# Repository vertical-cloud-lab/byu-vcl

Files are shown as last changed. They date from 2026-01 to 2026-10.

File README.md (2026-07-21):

# byu-vcl
Vertical Cloud Lab @ BYU

- [3D Printing SOP (Bambu Lab H2D, incl. multi-material PLA + TPU)](3d-printing-sop.md)
- [Thermo-Calc input for the 100 g ultrasonic atomization mixture](thermo-calc-100g-mixture-composition.md)

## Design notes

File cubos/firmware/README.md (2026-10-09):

# PANDA Arduino firmware — the VCL build

The Arduino Uno on `/dev/ttyACM0` runs **one** firmware that serves the
capper, the line-break sensor, the lights *and* the pipette plunger. Anything
flashed here affects the capper too, so nothing in this directory should be
applied casually.

Upstream: [`BU-KABlab/PANDA_Arduino`](https://github.com/BU-KABlab/PANDA_Arduino)
@ `228615b` ("fixed mixing function for pipette", 2025-08-27).

## 2026-10-07: the board runs `panda_vcl_p20gen2_tic796_fastmove_spread_20261007.hex`

Fix B for the TMC2209: the 10-01 image with spreadCycle instead of StealthChop, one line in
`setupMotor()` ([`panda-arduino-spreadcycle.patch`](panda-arduino-spreadcycle.patch)):

| call | was | now |
| --- | --- | --- |
| `setupMotor()` | `enableStealthChop()` | **`disableStealthChop()`** |

The library's `initialize()` turns `pwm_autoscale` off and nothing turns it back on. In
StealthChop that leaves `IRUN`/`IHOLD` scaling a fixed PWM amplitude instead of regulating the
current, about 0.1 A, and the plunger didn't move. In spreadCycle the chip regulates to them,
so the current table below is now what the coils get whenever the writes land. Built in
`~/panda_fw_vcl_tic796_fast_spread`, a copy of `~/panda_fw_vcl_tic796_fast`. The copy rebuilt
to the 10-01 image byte-for-byte before the edit. The new image is the same 17,468 bytes and
differs in one instruction: `andi r24, 0xFB` → `ori r24, 0x04`, setting GCONF bit 2
(`en_SpreadCycle`). `avrdude -U flash:v` matched the 10-01 image before the upload and this one
after it. The flash was read back first, as
[`../results/tmc2209_spreadcycle_20261007/flash_before_20261007.hex`](../results/tmc2209_spreadcycle_20261007/flash_before_20261007.hex).
On hardware: `tmc2209_probe.py` passed and `pipette_test` ran 12/12
([`../results/tmc2209_spreadcycle_20261007/`](../results/tmc2209_spreadcycle_20261007/README.md)).
The Tic ignores the UART writes, so this image also serves the Tic. To go back, flash
`panda_vcl_p20gen2_tic796_fastmove_20261001.hex` with the `avrdude` command at the end of this
file.

## 2026-10-01: the board ran `panda_vcl_p20gen2_tic796_fastmove_20261001.hex`

The 796 image with `MOVE_TO` sped up (speed change 3 in
[`../docs/pipette-setup-and-troubleshooting.md`](../docs/pipette-setup-and-troubleshooting.md#speed)).
Both changes since `panda-arduino-p20-and-driver-status.patch` are in
[`panda-arduino-tic796-and-fast-moveto.patch`](panda-arduino-tic796-and-fast-moveto.patch).

| constant / function | was | now |
| --- | --- | --- |
| `MOVEMENT_VELOCITY` | 2500.0 (~2,400 steps/s, ~3 mm/s) | **10000.0**: `stepMotor()`'s 100 µs floor, ~8,700 steps/s (~11 mm/s), the rate `ASPIRATE` already ran at because CubOS sends it speed 0 |
| `EJECT_VELOCITY` | — | **2500.0**, new |
| `movePipetteTo()` with no speed | everything at `MOVEMENT_VELOCITY` | any leg past `BLOWOUT_POSITION` (the tip-ejector push) at `EJECT_VELOCITY`; a move from below blowout goes fast to 32.5 first |

Built in `~/panda_fw_vcl_tic796_fast`, a copy of `~/panda_fw_vcl_tic796`:
17,468 bytes. `avrdude -U flash:v` matched the 09-30 image before the upload
and this one after it ([`../results/pipette_test_20261001/`](../results/pipette_test_20261001/SUMMARY.md)).
On hardware: `MOVE_TO 28.0` from 0 went from 9.29 s to 2.56 s, `MOVE_TO 46.5`
stayed at 4.65 s, and a post-run plunger `HOME` showed no lost steps. To go
back: flash `panda_vcl_p20gen2_tic796_20260930.hex` with the `avrdude` command at
the end of this file, or `pio run -e uno -t upload` in `~/panda_fw_vcl_tic796`.

## 2026-09-30: the board ran `panda_vcl_p20gen2_tic796_20260930.hex`

The pipette driver is now a Pololu Tic T500 in STEP/DIR mode, whose finest step
is 1/8 ([`../docs/tic-t500-pipette-setup.md`](../docs/tic-t500-pipette-setup.md)).
This image is `panda_vcl_p20gen2_20260917.hex` with two constants changed in
`include/Pipette.h`:

| constant | was | now |
| --- | --- | --- |
| `STEPS_PER_MM` | 1592.0 (TMC2209 at 1/16) | **796.0** (Tic at 1/8) |
| `MICROSTEPPING` | 16 | **8** (only feeds the TMC2209 setup call, which now writes to nothing) |

Built on the Pi from `~/panda_fw_vcl`, the tree that built the 09-17 image:
an unchanged rebuild reproduced that image byte-for-byte, and this one differs
from it in 5 bytes, all `ldi` immediates for those two constants. Flashed and
verified before and after with `avrdude -U flash:v`; record in
[`../results/pipette_test_20260930/`](../results/pipette_test_20260930/README.md).
796 is the safe choice while the scale is unconfirmed by a ruler: if 1592 were
right after all, every move would come out half as long rather than twice as
long. To go back: flash `panda_vcl_p20gen2_20260917.hex` with the `avrdude`
command at the end of this file.

The sections below describe the images before this one.

## ⚠️ 2026-09-17: a newer image is built and committed but **NOT flashed**

`panda_vcl_p20gen2_20260917.hex` corrects the plunger planes and the driver
current to Opentrons' own **P20 GEN2** figures (table below). It could not be
programmed: `avrdude` cannot sync with the board at any baud, because the
Arduino's serial link is corrupting data in both directions. Evidence and the
bench checks are in
[`../results/pipette_p20gen2_20260917/README.md`](../results/pipette_p20gen2_20260917/README.md).

**So the board still runs `panda_vcl_p20_20260915.hex`.** Once one `STATUS`
round-trip parses again, flash with:

```bash
cd ~/panda_fw_vcl && ~/.venvs/pio/bin/pio run -e uno -t upload --upload-port /dev/ttyACM0
```

`pio` is the way to do it — it drives the auto-reset correctly, where a bare
`avrdude` invocation on this Pi does not.

## What is on the board (2026-09-15)

| file | what it is |
| --- | --- |
| `flash_20260915T220346Z.hex` | **Backup of the flash as it was before this change.** Read with `avrdude -U flash:r:...:i` at 2026-09-15 22:03 UTC. Restores the board exactly. |
| `panda-arduino-p20-and-driver-status.patch` | The VCL delta against upstream `228615b`. **Regenerated 2026-09-17**: five files, +161/-12. Verified with `git apply --check` against a fresh clone at `228615b`, and the fresh clone builds. |
| `panda_vcl_p20_20260915.hex` | The image actually flashed on 2026-09-15, and **still what is on the board**. |
| `panda_vcl_p20gen2_20260917.hex` | The P20 GEN2 image. Built and verified, **not flashed** — see the warning above. 17 382 bytes, 53.9% flash, 1429 bytes RAM. |

The patch previously documented as "four files" also carries a
`platformio.ini` change (dropping `lib_extra_dirs = ~/Documents/Arduino/libraries`,
a path that does not exist on the Pi) that the earlier regeneration missed. It
is captured now.

**The backup proved the provenance.** Parsed and compared byte-for-byte, the
16 308 program bytes read off the board were **identical** to a local build of
upstream `228615b` — so the board really was running stock upstream, and the
VCL image is a provably minimal delta from it.

`panda_vcl_p20_20260915.hex` is the exact 17 370-byte image that was written and
verified by avrdude. A rebuild reproduced it bit-for-bit in one environment, but
**the build is not reproducible in general**: `platformio.ini` pins its library
dependencies with `^` ranges, so a clone that resolves a different minor version
builds a slightly different image (17 364 bytes in one such case). Flash the
committed hex if you want exactly what was on the board; rebuild from the patch
if you want the source of truth.

## Upstream `main` does not compile

`228615b` gives a default argument for `dwell_ms` in **both** the declaration
in `include/Pipette.h` and the definition in `src/Pipette.cpp`, which is a hard
C++ error:

```
src/Pipette.cpp:355:86: error: default argument given for parameter 4 of
  'bool mixInPlace(int, float, float, float)'
```

The patch drops the duplicate from the definition; the header keeps it, so the
default is unchanged. Worth sending upstream — as it stands nobody can build
`main`.

## What changed, and why

### Pipette constants — P20 GEN2, from Opentrons

The pipette on the head is a **P20 GEN2** — legible on the body in
`../results/pi5_des4_provision_20260914/pipette_label_p20_gen2.jpg` and in
campaign 36's `cam0_csi0` frame, and confirmed by Ben on 2026-09-17. Ursa's
records had said P300 GEN2, and the 2026-09-15 image was a hybrid: P300
plunger planes with P20 volume limits. Resolved in favour of the P20 GEN2.

Authority is Opentrons
`shared-data/pipette/definitions/1/pipetteModelSpecs.json`, keys
`p20_single_v2.0`/`2.1`/`2.2` (identical positions in all three). Opentrons
states plunger planes as signed offsets in a frame whose `top` is the home
reference; this firmware measures distance **downward** from home, so each
value is `top - <field>` with `top = 19.5`.

| constant | stock | 2026-09-15 | **2026-09-17** | why |
| --- | --- | --- | --- | --- |
| `MAX_VOLUME` | 300.0 | 20.0 | **20.0** | P20 GEN2. `STATUS` reported `max_vol: 300.00` for months. |
| `MIN_VOLUME` | 5.0 | 1.0 | **1.0** | P20 GEN2. The P300 clamp is why `ASPIRATE 0.5` always landed at 35.45: 0.5 clamped up to 5. |
| `PRIME_POSITION` | 36.0 | 36.0 | **28.0** | Opentrons `bottom` −8.5. 36.0 is the P300's plane. |
| `BLOWOUT_POSITION` | 44.0 | 44.0 | **32.5** | Opentrons `blowout` −13. |
| `DROP_TIP_POSITION` | 55.0 | 55.0 | **46.5** | Opentrons `dropTip` −27. Also the ceiling `moveTo` clamps at. |
| `UL_TO_MM` | 0.1098 | 1.8 | **1.34** | `1 / 0.746`, and 0.746 µL/mm is the asymptote of Opentrons' own `ulPerMm` table for `p20_single_v2.1`. The 1.8 was only `36.0 / 20`, i.e. read off a P300 plane. |
| `RUN_CURRENT_PERCENT` | 50 | 17 | **20** | → CS 6, **1.02 A peak** = Opentrons `plungerCurrent` 1.0 A. See the current note below. |
| `HOLD_CURRENT_PERCENT` | 30 | 10 | **5** | → CS 1, **0.29 A peak** = Opentrons `idleCurrent` 0.3 A. |

Two cross-checks that `UL_TO_MM 1.34` is derived rather than guessed:

- The same method applied to the P300 gives 9.1 µL/mm, reproducing
  `UL_TO_MM 0.1098` — the one constant in this firmware that was
  independently calibrated. So the method is validated against a known-good
  value.
- A full-scale 20 µL aspirate travels `20 × 1.34 = 26.8 mm` up from
  `PRIME_POSITION 28.0`, landing the plunger at **1.2 mm**: inside the 28 mm
  top-to-bottom stroke with a small dead band, which is how Opentrons has it.

**All three planes moved down, so every commanded plunger travel is shorter
than before** — the safe direction — and `0 < prime < blowout < drop_tip`,
which `aspirate`/`dispense`/`moveTo` rely on, still holds.

⚠️ **Nominal, not calibrated.** These are Opentrons' figures for the model,
not a measurement of this unit. `UL_TO_MM` needs a gravimetric check once
liquid actually moves.

These three planes now match CubOS's `p20_single_gen2` entry exactly; see
[`../patches/README.md`](../patches/README.md).

### Driver current — the sense resistor is 0.05 Ω, not 0.11 Ω

The 2026-09-15 value of 17 was scaled from an assumed 0.11 Ω sense resistor
and a 500 mA target taken from science-jubilee's Duet config. Both were wrong.
Ursa read `R1`/`R2` = **0.05 Ω** off the Adafruit 6121 schematic, and
Opentrons' own `p20_single_v2.x` runs the plunger at **1.0 A**, idling at
0.3 A. With `vsense = 0` (`enableVSense()` is never called) and the library's
`CS = map(percent, 0, 100, 0, 31)`:

```
I_rms = ((CS+1)/32) * (0.325 / (0.05 + 0.02)) / sqrt(2) = ((CS+1)/32) * 3.283 A
```

| percent | CS | I_rms | I_peak | |
| --- | --- | --- | --- | --- |
| 50 | 15 | 1.64 A | 2.32 A | stock — over the **breakout's** 2 A rating, not just the motor's |
| 17 | 5 | 0.62 A | 0.87 A | 2026-09-15 |
| **20** | **6** | **0.72 A** | **1.02 A** | Opentrons `plungerCurrent` |
| **5** | **1** | **0.21 A** | **0.29 A** | Opentrons `idleCurrent` |

Hold current is mapped to IHOLD **independently** of run current by this
library, not as a percentage *of* it — so the two rows have to be chosen
together. ⚠️ **Fit the Adafruit 1515 heat sink before running at this
current.**

⚠️ **Whether this table is in force depends on power-up order, and cannot be
read back yet.** `RUN_CURRENT_PERCENT` reaches the chip through
`setRunCurrent()`, a UART *write*. `UART` runs straight from A1 to `PDN_UART`,
writes need no reply, and SoftwareSerial's 9600 baud clears the datasheet's
9000 minimum — so whenever the Arduino boots with the 12 V already up (including
every time a host opens the port, which resets it), `setOperationModeToSerial()`
very probably lands, takes the VREF trimmer out of circuit, and this table
governs. If the Arduino boots before the 12 V, the writes reach an unpowered chip
and the trimmer governs until the next reset. So **keep the two matched**: VREF
at 0.55–0.59 V on the wiper gives 1.02–1.09 A peak, the same as the 20 row; it
has been at 0.586 V since 2026-09-26. Full clockwise on the Adafruit 6121 is
~1.5 A rms / 2.2 A peak — its 10 kΩ trimmer is fed from `5VOUT` through 33 kΩ —
not the ~3.3 A rms stated here until 2026-09-26. `IFCNT` will settle the
question once the bridge resistor is on the TX side. See §22.4–22.5 of
[`../docs/opentrons-pipette-wiring.md`](../docs/opentrons-pipette-wiring.md).

### The TMC2209 library is now vendored and patched

`lib/TMC2209/` in the firmware project holds a patched copy of the janelia
library: reads over `SoftwareSerial` cannot work unpatched, which is why
`CMD_PIPETTE_DRIVER_STATUS` always answered `comm = 0`. The patch is
[`../patches/tmc2209-softwareserial-read.patch`](../patches/tmc2209-softwareserial-read.patch);
it is **not** sufficient on its own — the bridge resistor also has to move to
the TX side. Vendoring into `lib/` rather than `.pio/libdeps/` is deliberate
and was verified, not assumed: a sentinel `#error` in the `lib/` copy fails
the build, so that copy is provably what compiles.

`PRIME_POSITION` 36.0, `BLOWOUT_POSITION` 44.0 and `DROP_TIP_POSITION` 55.0 are
**unchanged** — they are mechanical plunger positions, and `UL_TO_MM` 1.8 is
derived from `PRIME_POSITION`, so moving one means re-deriving the other.
They may still be P300 figures; a P20's usable travel is shorter, and
`DROP_TIP_POSITION` 55.0 in particular is worth checking against the real
plunger before anything relies on the ejector.

### New: `CMD_PIPETTE_DRIVER_STATUS = 29`

Ben bridged `RX_PIN` (A0) to `TX_PIN` (A1) with 10 kΩ on 2026-09-15, which is
what makes a TMC2209 read possible — PDN_UART is half duplex, so the driver
answers on the wire it was addressed on, and without the bridge the Arduino
could only ever talk.

Before this, `setupMotor()` wrote six registers and checked none of them, and
no command exposed driver state. A driver sitting at minimum current with its
output stage off was indistinguishable, at the serial port, from a healthy one.

```
OK:{"msg":"Driver status","v":[<comm>,<flags>,<current_scaling>]}
```

* `comm` — `0` no reply at all · `1` communicating but not set up (driver power
  was lost after `setup()`, so defaults reloaded) · `2` set up and communicating
* `flags` — bitmask, `DRVSTATUS_*` in `include/Pipette.h`: over-temperature
  warning/shutdown, short-to-ground A/B, low-side short A/B, **open-load A/B**,
  the 120/143/150/157 °C flags, stealthChop, standstill, hardware-disabled
* `current_scaling` — the driver's actual CS value, 0-31, or `-1` if unread

`open_load_a`/`open_load_b` answer the coil-continuity question without a
meter. Read it with CubOS's own link:

```python
from cubos.instruments.controllers.pawduino import PawduinoLink
link = PawduinoLink.acquire("/dev/ttyACM0", 115200); link.connect()
print(link.send_command(29, timeout=15))
```

## Rebuild / reflash / restore

PlatformIO lives in a user venv on the Pi (`~/.venvs/pio`), toolchain under
`~/.platformio` — no sudo, nothing system-wide.

```bash
git clone https://github.com/BU-KABlab/PANDA_Arduino.git ~/panda_fw_vcl
cd ~/panda_fw_vcl && git checkout 228615b
git apply ~/byu-vcl/cubos/firmware/panda-arduino-p20-and-driver-status.patch
~/.venvs/pio/bin/pio run -e uno -t upload --upload-port /dev/ttyACM0
```

To put the board back exactly as it was:

```bash
AVRDUDE=~/.platformio/packages/tool-avrdude/avrdude
CONF=$(find ~/.platformio -name avrdude.conf | head -1)
"$AVRDUDE" -C "$CONF" -c arduino -p atmega328p -P /dev/ttyACM0 -b 115200 -D \
    -U flash:w:~/byu-vcl/cubos/firmware/flash_20260915T220346Z.hex:i
```

Close every serial handle first — CubOS holds `/dev/ttyACM0` for the whole of a
run, and opening the port resets the board.

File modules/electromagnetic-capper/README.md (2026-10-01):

# Electromagnetic Vial Capper/Decapper Module

Magnet-based (rotation-free) vial capping/decapping module for automated liquid handling,
replicated from the **PANDA-film** self-driving lab developed by Keith A. Brown's group
(KABlab) at Boston University.

- **Paper:** Quinn, H.; Robben, G. A.; Zheng, Z.; Yan, J.; Li, Y.; Yang, Z.; Politi, M.;
  Peek, N.; Pozzo, L.; Werner, J. G.; Brown, K. A. *PANDA-film: an automated system for
  electrodeposition of polymer thin films and their wetting analysis.*
  [arXiv:2601.07043](https://arxiv.org/abs/2601.07043) (2026). CC BY 4.0.
  A copy is committed in [`paper/`](paper/) together with its license.
- **Source hardware/software repo:** [BU-KABlab/PANDA-BEAR](https://github.com/BU-KABlab/PANDA-BEAR) (GPL-2.0)
- **Arduino firmware:** [BU-KABlab/PANDA_Arduino](https://github.com/BU-KABlab/PANDA_Arduino)
- **Community discussion:** [Electromagnetic capper thread on accelerated-discovery.org](https://accelerated-discovery.org/t/electromagnetic-capper/579)
- **Tracking issue:** vertical-cloud-lab/byu-vcl#147

## How it works

Commercial capper/decappers grip and rotate caps. This design avoids rotary motion
entirely: a small **5 V, 50 N electromagnet** mounted on the gantry head picks up
custom **press-fit caps that carry a steel disc**, and an **IR break-beam sensor**
confirms successful cap pickup and replacement (paper Figure 2A–B).

Custom caps are fabricated by:

1. 3D printing the cap body in **PLA** (the authors used a Bambu A1; any well-tuned FDM
   printer works) — [`cad/VialCap16mm.step`](cad/VialCap16mm.step)
2. Filling the cap interior with **PDMS (Sylgard 184, 10:1 by weight base:curing
   agent)** for chemical resistance and sealing. The paper calls the second component
   the "crosslinker"; on the Sylgard 184 kit itself it is labeled **Silicone Elastomer
   Curing Agent** — same thing.
3. Affixing a **steel disc with 3M adhesive** into the recessed region on top of the cap

The electromagnet sits in a 3D-printed holder
([`cad/PAW-V2-ElectromagnetMount.step`](cad/PAW-V2-ElectromagnetMount.step)) alongside
the IR break-beam sensor. It is switched by an Arduino Uno through an IRLZ44 logic-level
MOSFET with a 1N5819 flyback diode across the coil.

**Validated performance (paper §3.1, Figure 2C):** 100% capping/decapping success with
tolerance to **~3 mm of vertical approach-height misalignment**, tested across five
independently fabricated caps × 10 decap/recap cycles per height step (0.2 mm steps).

## Contents

| Path | Description |
|---|---|
| [`BOM.md`](BOM.md) | Bill of materials for the ME order (procure + print + fabricate) |
| [`paper/panda-film-2601.07043.pdf`](paper/panda-film-2601.07043.pdf) | The paper (arXiv:2601.07043, CC BY 4.0) |
| [`paper/LICENSE-CC-BY-4.0.txt`](paper/LICENSE-CC-BY-4.0.txt) | Paper license |
| [`cad/VialCap16mm.step`](cad/VialCap16mm.step) | Custom vial cap (print one per stock vial) |
| [`cad/PAW-V2-ElectromagnetMount.step`](cad/PAW-V2-ElectromagnetMount.step) | Electromagnet + sensor mount for the gantry head |
| [`cad/9VialHolder20mL_TightFit.step`](cad/9VialHolder20mL_TightFit.step) | 9-position 20 mL vial rack for the deck |
| [`cad/LICENSE-GPL-2.0.txt`](cad/LICENSE-GPL-2.0.txt), [`cad/NOTICE.txt`](cad/NOTICE.txt) | License/notice for the CAD files (from PANDA-BEAR) |

Note on sources: the paper was submitted to arXiv as PDF only — no LaTeX source is
available from the e-print endpoint (it returns the identical PDF), so only the PDF is
committed here.

## Build references

- [PANDA-BEAR Construction Guide](https://github.com/BU-KABlab/PANDA-BEAR/blob/main/documentation/Construction.md) — PAW assembly, parts checklist
- [PANDA-BEAR Arduino Wiring](https://github.com/BU-KABlab/PANDA-BEAR/blob/main/documentation/Arduino-Wiring.md) — circuit diagrams (electromagnet MOSFET driver, IR sensor)
- [PANDA-BEAR full BOM](https://github.com/BU-KABlab/PANDA-BEAR/blob/main/documentation/documents/bom.md) — complete PANDA-film parts list (superset of this module)
- [3D print files (all)](https://github.com/BU-KABlab/PANDA-BEAR/tree/main/documentation/3D-prints)

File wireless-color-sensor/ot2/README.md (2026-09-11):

# OT-2 colour X-scan: pick up from slot 10, read three X positions over the scan slot

The test @timothy-commins asked for in
[issue #33](https://github.com/vertical-cloud-lab/byu-vcl/issues/33):

> make the color sensor pick up the enclosure from well 10, and then place it
> into 3 different places in the x direction on well 8. the test will then
> test the color at each of the 3 places in well 8

```
seated baseline read
  -> pick up the enclosure from slot 10        (proven descent/entry/press recipe)
  -> grip check                                (the sensor's own counts confirm the lift)
  -> carry to slot 8, x = centre - 30 mm       descend to the read height, read 3x
  -> carry to slot 8, x = centre               descend to the read height, read 3x
  -> carry to slot 8, x = centre + 30 mm       descend to the read height, read 3x
  -> carry back to slot 10, reseat, home
  -> reseat-confirm read
```

Every reading goes to `digital-wetlab.sensor-data` in MongoDB and to a local
JSON file.

## Run it

The script has to run on **the machine with the USB-Ethernet cable to the
OT-2**. The robot answers only on the link-local address
`169.254.51.252:31950`, and the same machine needs internet for HiveMQ and
MongoDB — so it must be one host, not two.

As of 2026-09-09 that machine is the Pi behind **`RPI_STREAM_CAM_HOSTNAME`**,
not the one behind `OT2_STREAM_CAM_HOSTNAME`. The adapter is a Realtek RTL8153
on `eth1` holding `169.254.210.205/16`. The `OT2_STREAM_CAM_HOSTNAME` Pi has no
ethernet interface and no USB devices at all, so `169.254.51.252` times out from
there — which is what "the OT-2 is not answering" looked like in the previous
session. Check with `ip -4 -br addr` before concluding the robot is down.

The venv is already set up on that Pi at `~/.venvs/xscan` (`paho-mqtt`,
`pymongo`, `requests`; the system Python 3.13 is externally managed, hence the
venv). To rebuild it elsewhere:

```bash
python3 -m venv ~/.venvs/xscan
~/.venvs/xscan/bin/pip install paho-mqtt pymongo requests

export MQTT_BROKER=... MQTT_PORT=8883 MQTT_USERNAME=... MQTT_PASSWORD=...
export PICO_ID=... MONGODB_URI=... MONGODB_DATABASE=digital-wetlab
```

Then, in order:

```bash
# 0. is the enclosure actually on the deck? One HTTP call, no motion.
~/.venvs/xscan/bin/python deck_photo.py -o deck.jpg

# 1. confirm the pickup coordinate. Homes, hovers the BARE nozzle 30 mm above
#    the computed pickup point, and stops. Slide the base under it.
~/.venvs/xscan/bin/python run_xscan_test.py --align

# 2. sensor + database only -- the robot never moves
~/.venvs/xscan/bin/python run_xscan_test.py --dry-run

# 3. the real test
~/.venvs/xscan/bin/python run_xscan_test.py
```

**Step 0 is not optional when nobody is standing at the robot.** The grip check
catches an empty pickup, but only after the nozzle has already descended and
pressed at slot 10. A photograph costs one HTTP call and answers the same
question before anything moves — on 2026-09-09 it found the deck completely
bare, with nothing in slot 10 or slot 8.

Run `--align` **every time the base is moved**. The slot-10 pickup coordinate
below is the proven slot-8 coordinate translated by the OT-2 slot pitch, not a
measured one — `--align` turns that assumption into a 30-second visual check
before anything presses down on the enclosure.

## Deck layout

| | |
|---|---|
| Enclosure base | slot **10**, socket at (36.55, 315.5) |
| Read positions | slot **8**, x = 166.38 / 196.38 / 226.38, all at y = 225.0, z = 120.0 |
| Pipette | `p300_single_gen2`, left mount |

The pickup offset within the slot is (36.55, 44.0) — the same offset the
[PR #60 sessions](../camera/) used for the base in slot 8, so slot 10 gives
(0, 271.5) + (36.55, 44.0). The read Y uses the same within-slot 44.0 mm, which
lands on y = 225.0 in slot 8 — the exact Y those camera-verified sessions ran at.

**Only X changes between the three reads.** The 2026-08-10 session measured
that raw counts are dominated by pose — the same sensor read ~15× higher lifted
than seated — so a scan that also varied Y or Z would be measuring the pose
rather than the sample. Y, Z, settle time and command values are identical at
all three positions.

At z = 120 the nozzle is 29.5 mm above its press depth, so the enclosure's
aperture sits about **29.5 mm above the deck**. If you put a plate or a
backlight in slot 8, raise or lower with `--read-z`; the aperture height is
always `read_z - 90.5`.

## Motion recipe

Unchanged from the recipe that completed **9 of 9** pick-and-reseat cycles in
July/August 2026 ([`../camera/pickup-test-2026-08-10-pick-and-reseat/`](../camera/pickup-test-2026-08-10-pick-and-reseat/)).
Only the start slot and the read positions are new.

| stage | value |
|---|---|
| Descent ladder | z 170 → 150 → 120 → 105 → 101 → 99 |
| Straight entry | z = 95 @ 5 mm/s |
| Press | z = 90.5 @ 5 mm/s (≥ 7 mm engagement, so eject works later) |
| Lift test | z = 110 + 4 s dwell |
| High lift | z 130 → 150 → 170 @ 15 mm/s |
| Carry | 8.5 mm segments @ 10 mm/s |
| Read | descend to z = 120 @ 10 mm/s, settle 1.5 s, read ×3 |
| Drop-off | pickup x − 6 mm (anti-tilt), staged descent 130 → 110 → 108 → 101 → 95.5 |
| Eject | `dropTipInPlace`, clear to z = 128, home |

The staged climbs and segmented carries are not decoration: on 2026-07-31 the
module came off the nozzle during a single long Z move.

## Safety behaviour

**Grip check.** After the lift test the script takes two readings and compares
them with the seated baseline. Lifting the enclosure off its base uncovers the
aperture, which raised the counts ~15× in the 2026-08-10 session. If the counts
do not rise by at least 2× (`--grip-ratio`), the nozzle came up empty and the
script aborts before the carry rather than flying an empty nozzle to slot 8 and
then "reseating" it next to a still-seated enclosure. `--skip-grip-check`
disables it.

**Reseat on failure.** Any exception during the carry or the reads triggers the
reseat leg and a home before the script exits, so the enclosure is not left
hanging. If that also fails, the message points at
[`../cad/recover_reseat.py`](../cad/recover_reseat.py), which recovers a
stranded grip — but look inside the robot first.

**Preflight.** Before the robot is touched: the broker connection is proved by
publishing a probe to our own topic and waiting for the echo (a broker can grant
a subscription and then deliver nothing), the sensor is proved by taking the
seated baseline, and every coordinate is bounds-checked against its slot.

## Files

| file | what it is |
|---|---|
| `run_xscan_test.py` | the test |
| `sensor_read.py` | one MQTT connection held open for the run; `read()` returns the 8 channels |
| `deck.py` | OT-2 slot origins and slot/offset maths, with no `opentrons` dependency |
| `check_reachability.py` | pushes every planned coordinate through the Opentrons simulator |
| `stream_index.py` | every reading → its UTC instant → a timestamped livestream link |
| `frames_from_stream.py` | pulls one frame per measurement and OCR-verifies it against the clock burned into the stream |
| `plot_spectra.py` | 300 px spectra in the light-mixing `basic_plotting.py` style |
| `build_gallery.py` | stitches frame + spectrum + link into `measurement-gallery.md` |
| `stream_grab_pi.py` | the Pi-side half of the frame grab (lives there as `~/ytframes/grab.py`) |
| `led_probe.py` | zero-motion check of whether the module's LEDs respond (they do not) |
| `deck_photo.py` | one HTTP call to the OT-2's own overhead camera |

## Lining a reading up against the livestream

`python3 stream_index.py` writes `measurement-stream-index.{json,md}`: all 114
readings of the 2026-09-09 session with a UTC instant and a `?t=` link into the
archived stream. `frames_from_stream.py` then pulls the frame at each instant.

Two things to know before trusting a link:

* **The archive timeline is not wall clock.** For `bQDrYpT3vaE` it runs 67 s
  behind `release_timestamp` from the third hour onward — a step, not a drift.
  That is more than one scan position, so `--offset-shift` is not cosmetic.
* **The stream burns a `%Y-%m-%d_%H-%M-%S` clock (lab local, UTC−6) into every
  frame**, which is how the offset is verified rather than assumed. Every
  committed frame records its OCR'd clock in `frames/frames.json`.

YouTube refuses player extraction from a GitHub Actions runner; the fetching
half runs over SSH on the stream-cam Pi (`~/ytframes/grab.py` there).

## Options

```
--home-slot 10 --scan-slot 8      which slots to use
--base-dx / --base-dy             where the socket sits within the home slot
--scan-dx -30,0,30                X offsets from the scan slot's centre (any number of them)
--scan-dy 44.0                    within-slot Y for the reads
--read-z 120 --carry-z 170        heights
--press-z 90.5                    pickup press depth; lower = deeper = tighter fit
--reads 3                         readings per position
--rgb 0,0,0                       R,Y,B sent with each read command
--align / --dry-run / --simulate  the three rehearsal modes
--no-mongo --out results.json     where the data goes
```

`--simulate` prints the whole motion plan with no robot and no sensor — useful
for checking a changed layout before taking it anywhere near hardware.

## What has been verified, and what has not

Verified on 2026-09-04 from CI:

- `sensor_read.py` against the live board — 8 channels back in 1.5 s.
- `--dry-run` end to end — baseline reads, MongoDB write into
  `digital-wetlab.sensor-data`, JSON output.
- `check_reachability.py` — all 28 planned coordinates in bounds for a
  left-mount P300; `deck.py`'s slot origins match the packaged Opentrons deck
  definition. Negative controls confirm the checker has teeth: `--scan-dx
  -100,0,100` is rejected as off-slot and `--read-z 250` is rejected as above
  the 218 mm Z limit.
- `--simulate` — 72 moves planned, segmentation and staging as intended.

Not verified on 2026-09-04: **the motion itself.** The OT-2 did not answer on
`169.254.51.252`, which was read at the time as a disconnected USB-Ethernet
adapter.

### 2026-09-09 — the robot answers; the deck is empty

That reading was half right. The adapter was never missing, it is on the *other*
Pi (see [Run it](#run-it)). From `RPI_STREAM_CAM_HOSTNAME` the robot answers
immediately:

```
GET /health -> 200  {"name": "OT2CEP20210722R13", "robot_model": "OT-2 Standard",
                     "api_version": "8.8.1", "system_version": "v1.19.6"}
GET /instruments    -> p300_single_gen2, left mount, ok=true
GET /calibration/status -> deckCalibration OK (2026-01-27)
```

Also verified this session, from the Pi that would drive the run:

- Sensor over MQTT — 8 channels, total 770 ± 1 across five reads, ~1.4 s each.
- `--dry-run` — broker delivery PASS, baseline reads, 2 documents written to
  `digital-wetlab.sensor-data`, JSON out.
- `--simulate` — 72 moves.
- `check_reachability.py` — 28/28 coordinates in bounds, slot origins match the
  packaged deck definition.
- **The maintenance-run command path, on the real robot.** Create run →
  `loadPipette` → `home` → `savePosition` → delete, all succeeded: pipette
  loaded in 2.4 s, home in 12.5 s, nozzle parked at (384.05, 349.93, 199.60).
  This is the path every move in the test goes through, and it had never been
  exercised before. Home was safe to run precisely because the deck was
  photographed empty first.

**The motion still did not run, for a different reason: the deck is bare.**
`deck_photo.py` shows all eleven slots empty — no enclosure, no base in slot 10,
nothing in slot 8. Running the test in that state would have descended on an
empty slot, come up with nothing, and aborted at the grip check without
measuring anything.

So the remaining blocker is now purely physical: stand the enclosure on its base
in slot 10, then run step 0, `--align`, and the test.

### 2026-09-09 — slot 7 at two heights; the LEDs were off the whole time

Two more complete cycles, both with slot 7 empty: the run asked for on #197
(`--scan-slot 7 --read-z 125`) and a control at the previous height
(`--scan-slot 7 --read-z 120`). The control exists because the requested run
changes both the slot and the height at once, so alone it cannot attribute the
difference to either. Grip check 5.1× and 5.3×; reseat confirmed on both.

Full write-up and data: [`results-slot7-2026-09-09.md`](results-slot7-2026-09-09.md).

Two things came out of it that change how the test should be run:

- **`--rgb` defaults to `0,0,0`, so every scan measures ambient light only.**
  The module's own illumination is never switched on. *Superseded in part later
  the same day:* `--rgb` turns out to be **inert** — the board acknowledges every
  level and colour but nothing lights (`led-probe-2026-09-09.json`), so "set
  `--rgb`" is not an available fix. Controlled illumination needs a working light
  source in the enclosure. This still reframes the "46% swing" finding: it is a
  symptom of reading with no illumination, not an inherent property of the deck.
- **Raising the aperture makes everything worse.** 5 mm higher cost 9–42% of the
  signal and made read-to-read repeatability 30–300× worse (0.03–0.07% at
  z 120 against 1–11% at z 125), and reversed the sign of the positional
  gradient. Slot 7 at z 120 gives ~7000 counts, a −5.5% gradient over 60 mm and
  reads that agree to within 2–5 counts; it beats both slot 8 and the raised
  pose on every measure. Default to it.

### 2026-09-09 — read z 129 with a 0.5 mm deeper press

Requested on #197 after the module worked loose and came off its base at the end
of the previous session: read 1 mm higher, press 0.5 mm deeper for a tighter fit.
`--press-z` was added for it, and it shifts the release height by the same delta
so the module is set down from the height the proven recipe used rather than
dropped from 0.5 mm up.

    run_xscan_test.py --scan-slot 7 --read-z 129 --press-z 90.0

Cycle completed, grip 4.6×, reseat confirmed at 436 against a seated 445. Full
write-up: [`results-z129-press90-2026-09-09.md`](results-z129-press90-2026-09-09.md).

Three things worth carrying forward:

- **A deeper press also raises the read height.** Seating the nozzle further into
  the socket makes the module ride higher on it, so `--read-z 129 --press-z 90.0`
  puts the aperture 39.0 mm off the deck — 1.5 mm above the previous run, not the
  1.0 mm the `--read-z` number alone suggests. `aperture_height_mm` in the run
  JSON is the number to compare across runs, not `--read-z`.
- **One clean cycle does not validate a grip fix.** The previous session's
  three-position cycle also completed cleanly; the module was lost during the
  longer second cycle that followed. And the grip *ratio* is a light reading at
  the lift height, not a measure of fit — a deeper press moves the aperture, so
  the ratio shifts for reasons unrelated to how tightly the module is held.
- **Bare deck is not spectrally flat, and differs by position.** At x = 93.88 the
  620 nm share is 28.6% against 20.9% at the slot centre, in the empty run and
  both paint runs alike. A per-position empty reference is the only valid
  baseline; "looks reddish" is not evidence of a red sample.

## 2026-09-09, late — why only yellow ever registers (no motion)

Re-analysis of every scan on record, prompted by the question on #197: if the
aperture clears the deck and passes over a vial at each stop, why does only one
colour show? Full write-up:
[`results-why-only-yellow-2026-09-09.md`](results-why-only-yellow-2026-09-09.md);
regenerate the figure with `python3 plot_why_only_yellow.py`.

- **Read height decides whether this instrument works.** Spread of the spectral
  shape across the three stops of an **empty** slot 7, worst channel, in points of
  share: **0.14 at z 120 · 1.52 at z 125 · 7.69 at z 128.** Fifty-five times worse
  for an 8 mm rise, with nothing on the deck. The colour effects reported earlier
  in the day are ~1.3 points, i.e. smaller than the artefact at the height they
  were measured at.
- **The height needed to clear a tall vial is the height at which measuring
  stops working.** Prefer flat opaque targets at z 120 over vials at z 128.
- **Occlusion and yellow paint have the same spectrum.** The room light carries 4×
  more flux in 583–670 than in 410–470, and 440/470 sit on a white LED's blue pump
  peak while 410 sits below it. So losing sight of the cool component reads as
  "440/470 down, 410 flat, red up" — indistinguishable from a yellow absorber
  without an illuminant of your own. Blue samples have no flux to reflect; red
  samples darken an already-red background, which is the artefact's own signature.
- **Check a claimed detection in absolute counts.** The "yellow" at x = 33.88 came
  with the total up 17% and 410 nm up 12% while 440 nm fell 25%. An absorber does
  not raise the total, and yellow's absorption edge is monotone below ~480 nm, so
  it must cut 410 at least as hard as 440. That was the room light changing between
  two runs six minutes apart, not a sample.
- **To settle it: move the sample, re-scan.** If the feature follows the vial it is
  real; if it stays at the same X it is the machine.

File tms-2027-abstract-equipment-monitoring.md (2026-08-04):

# TMS 2027 Abstract — Livestreaming Cameras for Equipment Monitoring

- **Meeting:** TMS 2027 Annual Meeting & Exhibition, Orlando, FL, March 14–18, 2027
- **Presentation type:** Poster
- **Target symposium:** *AI-Enabled Materials Processing: Integrating Accelerated Experimental Workflows and Processing-Aware Machine Learning* (Data-Driven and Computational Materials Design track; [flyer 021](https://www.tms.org/tms2027/downloads/flyers/TMS2027-CFA-Flyer-021.pdf))
  - The flyer explicitly welcomes "real-time process monitoring," "high throughput and data-aware experimental design," and "closed-loop experimental workflows that integrate synthesis, processing, characterization, testing, and iterative model-guided refinement" — the enabling-technology angle for accelerated/self-driving experimental workflows.
  - Alternate: *AI/ML/Data Informatics for Materials Discovery: Bridging Experiment, Theory, and Modeling* ([flyer 022](https://www.tms.org/tms2027/downloads/flyers/TMS2027-CFA-Flyer-022.pdf)) — lists "FAIR data principles, metadata frameworks, provenance, and interoperable infrastructure" as a topic of interest.
- **Abstract deadline:** July 1, 2026 (per flyer key dates)
- **Presenter:** Seth Leavitt

## Title

**Low-Cost Open-Source Camera Modules for Continuous Monitoring of Self-Driving Laboratories**

## Authors and Affiliations

| # | Author | Affiliation(s) | Role |
|---|---|---|---|
| 1 | Seth Leavitt | BYU Mechanical Engineering | Presenter |
| 2 | Yanghuang Liu | Acceleration Consortium, University of Toronto | Co-author |
| 3 | Jonathan Woo | Acceleration Consortium, University of Toronto | Co-author |
| 4 | Sterling G. Baird | BYU Mechanical Engineering; Acceleration Consortium, University of Toronto | PI |

## Abstract

*(Word limit: 150; current version: 147 words)*

As laboratories move toward higher autonomy, continuous equipment monitoring becomes
essential for debugging, provenance, and safety — echoing recent calls for aviation-style
"black box" recording in self-driving laboratories (SDLs). We present a fully open, low-cost
(<$100/module), many-camera, multi-site livestreaming infrastructure for SDL operations.
Unlike task-specific computer vision for real-time process control, each equipment module
receives a dedicated passive camera with tunable frame rate and resolution and failsafe
auto-restart for unattended operation. Dozens of modules deployed across multiple
institutions have achieved >99% uptime while collecting tens of thousands of hours of video.
Streams linked to timestamps and experiment metadata provide a visual audit trail
complementing structured records; the footage also yields heuristic utilization estimates
and, prospectively, robot-learning training data. Cameras capture only operators' hands and
forearms, a privacy-by-design choice for shared facilities housing furnaces, synthesis
platforms, and characterization instruments. All hardware, firmware, and documentation are
openly available (https://ac-training-lab.readthedocs.io/en/latest/devices/picam.html).

<!-- Source references: byu-vcl issue #9; AC Training Lab picam docs; AccelerationConsortium/streamingLambda -->
<!-- Framing informed by Edison Scientific feedback (PR #146): infrastructure novelty, visual audit trail,
     heuristic utilization, robot-learning as future work, black-box/provenance discourse (Leong et al. 2025),
     democratized SDL literature (Lo et al. 2024; Pelkie et al. 2025), materials-specific examples for TMS. -->

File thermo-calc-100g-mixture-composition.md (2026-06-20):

# Thermo-Calc input for the 100 g ultrasonic atomization mixture

This note converts the recorded **100 g mixture** in [issue #16 comment 4012488827](https://github.com/vertical-cloud-lab/byu-vcl/issues/16#issuecomment-4012488827) into a Thermo-Calc-friendly elemental composition in **wt.%**.

## Source masses

| Component | Measured mass (g) |
| --- | ---: |
| 1100 Al wire | 38.1640 |
| Si powder | 20.3042 |
| AlSi10Mg powder | 41.5472 |
| Total | 100.0154 |

## Composition assumptions

1. **1100 Al wire**  
   Treat as Al for the recommended Thermo-Calc input. AA1100 is **99.0 wt.% Al minimum**, but the supplied repo docs do not resolve the remaining trace-element breakdown tightly enough to support a better explicit element-by-element entry.

2. **Si powder**  
   The SDS in this repo (`silicon-powder-mcmaster-carr-sds-2014400 SDS SI101 011020.pdf`) lists **Si = 98.0-99.5 wt.%**. For a single nominal Thermo-Calc input, use **99.0 wt.% Si**.

3. **AlSi10Mg powder**  
   The [MSE Supplies product page](https://www.msesupplies.com/products/mse-pro-alsi10mg-aluminum-based-metal-powder-for-additive-manufacturing-3d-printing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) for the 15-45 um powder lists:
   - **Si = 9.0-11.0 wt.%**
   - **Mg = 0.2-0.45 wt.%**
   - **Al = balance**
   - trace limits: Fe <= 0.55, Mn <= 0.45, Cu <= 0.1, Ti <= 0.15, Zn <= 0.1, Sn <= 0.05, Pb <= 0.05 wt.%

For the nominal Thermo-Calc input below, use the midpoint values **Si = 10.0 wt.%** and **Mg = 0.325 wt.%**, so **Al = 89.675 wt.%** for the AlSi10Mg fraction.

## Recommended Thermo-Calc input (nominal)

Using the assumptions above and renormalizing to 100 wt.% gives:

| Element | wt.% |
| --- | ---: |
| Al | 75.56 |
| Si | 24.30 |
| Mg | 0.14 |

If Thermo-Calc needs a single composition, this is the cleanest input to start with.

## How that nominal composition was obtained

### Nominal element masses before renormalization

| Source | Al (g) | Si (g) | Mg (g) |
| --- | ---: | ---: | ---: |
| 1100 Al wire (treated as Al) | 38.1640 | 0.0000 | 0.0000 |
| Si powder (99.0 wt.% Si) | 0.0000 | 20.1012 | 0.0000 |
| AlSi10Mg powder (Al 89.675 / Si 10.0 / Mg 0.325 wt.%) | 37.2575 | 4.1547 | 0.1350 |
| Total modeled mass | 75.4215 | 24.2559 | 0.1350 |

These modeled masses sum to **99.8124 g**, so they were renormalized to 100 wt.% for the Thermo-Calc entry.

## Sensitivity window from supplier/datasheet ranges

If you want to bracket the uncertainty from the Si powder purity and the AlSi10Mg composition ranges, the modeled blend is approximately:

| Element | Low wt.% | High wt.% |
| --- | ---: | ---: |
| Al | 74.94 | 75.88 |
| Si | 23.63 | 24.77 |
| Mg | 0.08 | 0.19 |

## Practical recommendation

For the first Thermo-Calc AM Module run, use:

- **Al 75.56 wt.%**
- **Si 24.30 wt.%**
- **Mg 0.14 wt.%**

This is an **alloy blend chemistry**, not a molecular stoichiometric formula. If the Thermo-Calc team wants trace impurities (Fe, Cu, Mn, Zn, Ti, etc.) modeled explicitly, the next step should be to obtain a supplier certificate of analysis for the exact AA1100 wire and AlSi10Mg powder lots.

## Sources

- [Issue #16 comment with the 100 g measured masses](https://github.com/vertical-cloud-lab/byu-vcl/issues/16#issuecomment-4012488827)
- `silicon-powder-mcmaster-carr-sds-2014400 SDS SI101 011020.pdf`
- `aluminum-1100-wire-sds-0217200 SDS Alum 041116.pdf`
- [MSE Supplies AlSi10Mg 15-45 um product page](https://www.msesupplies.com/products/mse-pro-alsi10mg-aluminum-based-metal-powder-for-additive-manufacturing-3d-printing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)

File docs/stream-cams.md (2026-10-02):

# Stream cams

The lab's livestream cameras run the Acceleration Consortium
[picam client](https://ac-training-lab.readthedocs.io/en/latest/devices/picam.html)
(`device.py` from `AccelerationConsortium/ac-training-lab`), which pipes `rpicam-vid`
into `ffmpeg` and pushes RTMP to the *BYU VCL Hardware Streams* YouTube channel. Each
camera's settings live on its Pi, in a file that also holds a secret, so none of it is
in this repo. This page records what is set and what has been changed.

## `picam-ot2`: now pointed at the atomizer room

| | |
| --- | --- |
| Pi | Raspberry Pi Zero 2 W behind `OT2_STREAM_CAM_HOSTNAME` (user `OT2_STREAM_CAM_USERNAME`, sudo password `OT2_STREAM_CAM_PASSWORD`), Camera Module 3 (imx708), Debian 13 |
| Points at | the atomizer room, as of 2026-10-01, **not the OT-2**. It streams as `CAM_NAME = "picam-ot2"` and `WORKFLOW_NAME = "atomizer"`, so broadcasts are titled *atomizer stream picam-ot2, …* and go into the [*atomizer Livestreams Playlist*](https://www.youtube.com/playlist?list=PLeosQpHvsjiY) (`PLeosQpHvsjiY`). Until 2026-10-01 17:38 MDT the workflow was `OT-2`, whose broadcasts the Lambda files into the *OT-2 Livestreams Playlist* (`PLdKz1vXA-rfQ`). The robot itself is cabled to the Pi behind `RPI_STREAM_CAM_HOSTNAME` ([`wireless-color-sensor/ot2/README.md`](../wireless-color-sensor/ot2/README.md#run-it)) |
| Client | `~/ac-training-lab/src/ac_training_lab/picam/device.py`, upstream `87a3ccb` plus a local patch, run by `device.service`. The patch adds `SENSOR_MODE`, and on the libx264 path a 2 s keyframe interval and (since 2026-10-01) `-r FRAME_RATE`. Since 2026-10-01 18:52 it also passes `--flush` to `rpicam-vid` and `-flags low_delay` to ffmpeg's video input; see [The overlay that skipped seconds](#the-overlay-that-skipped-seconds). Since 19:55 it also reads an optional `PIXELATE_BLOCKS`; see [Pixelation](#pixelation). The file before the `-r` change is `~/device.py.bak-2026-10-01`, before the `--flush` change `~/device.py.bak-2026-10-01-flush`, and before pixelation `~/device.py.bak-2026-10-01-pixelate` |
| Settings | `my_secrets.py` in the same directory, mode `600`. It also holds the Lambda URL, so read individual lines rather than `cat` it |
| Watchdog | `stream-watchdog.timer` runs `/usr/local/bin/stream-watchdog.sh` every minute. It restarts `device.service` after 3 checks in a row with no RTMP bytes acknowledged, at most 6 times a day by default |
| Reboots | root crontab, `0 5,13,21 * * *`. Each boot starts a fresh broadcast from whatever `my_secrets.py` says |

### Current settings

| Setting | Value |
| --- | --- |
| `CAM_NAME` | `"picam-ot2"` |
| `WORKFLOW_NAME` | `"atomizer"`. Was `"OT-2"` until 2026-10-01, see [Renaming the workflow](#renaming-the-workflow) |
| `RESOLUTION` | `"144p"` (256×144). Was `"720p"` until 2026-10-01 17:01 and `"240p"` until 18:52, see [Change log](#change-log) |
| `FRAME_RATE` | `2`. Was `10` until 2026-10-01 |
| `SENSOR_MODE` | `"2304:1296"`, the full-field binned imx708 mode. Without it the sensor picks a cropped mode for small outputs |
| `TIMESTAMP_OVERLAY` | `True`: lab local time, top left. This also forces the libx264 re-encode |
| `PIXELATE_BLOCKS` | `128`: the picture is averaged into 128×72 solid blocks, 2×2 px each at 144p, before the timestamp is drawn, so the timestamp stays sharp. Added 2026-10-01 19:55 at `32`, and `128` since 22:59; see [Pixelation](#pixelation) |
| `CAMERA_VFLIP` / `CAMERA_HFLIP` | `True` / `True` (the camera is mounted upside down) |
| `CAMERA_ROTATION` | `0` |
| `PRIVACY_STATUS` | `"public"` |

### Changing a setting

Edit the one line, then restart once:

```bash
ssh "$OT2_STREAM_CAM_USERNAME@$OT2_STREAM_CAM_HOSTNAME" \
  'cd ~/ac-training-lab/src/ac_training_lab/picam &&
   sed -i "s/^RESOLUTION = .*/RESOLUTION = \"144p\"/" my_secrets.py &&
   grep -n "^RESOLUTION" my_secrets.py &&
   sudo -S -p "" systemctl restart device.service' <<< "$OT2_STREAM_CAM_PASSWORD"
```

`device.py` reads `my_secrets.py` only when it starts, so nothing changes until the
restart. A restart ends the current broadcast and creates a new one with a new video ID, and the
stream is off the air for 20–30 s while that happens. Every start also counts against `device.service`'s
`StartLimitBurst=3` per hour, so don't restart in a loop. `systemctl reset-failed device.service`
zeroes that count, if a third restart within the hour can't wait. If systemd does give up, the
watchdog starts the unit again after 10 minutes.

`RESOLUTION` accepts `144p`, `240p`, `360p`, `480p`, `720p` and `1080p`. The overlay font
scales as `max(16, height // 20)`: 36 px at 720p, 16 px at 240p and 144p. At 144p the
timestamp's box covers about three quarters of the frame's width.

**Read the `Output #0` line after changing `FRAME_RATE`.** ffmpeg takes its output rate from
its own estimate of the piped input's rate (the `tbr` on the `Input #1` line), and at low rates
that estimate wanders. The first start at `FRAME_RATE = 2` estimated 1.50, so ffmpeg sent
1.5 fps and dropped a quarter of the frames. The next start estimated 2. At 10 fps the estimate
was 20 and ffmpeg still sent 10, which is why this never showed before. The `-r FRAME_RATE` in
the local patch pins the output to the camera's rate whatever the estimate, so expect
`Output #0 … 2 fps`.

**`systemctl status device.service` prints the stream key.** Its process list shows ffmpeg's
full command line, RTMP URL and all. The journal's `Streaming to:` and `create` response lines
carry it too. For the unit's state use `systemctl show device.service -p ActiveState -p SubState
-p ActiveEnterTimestamp -p NRestarts`, and pipe journal output through
`sed -E 's#live2/[A-Za-z0-9_-]+#live2/<key>#g'`.

### Pixelation

`PIXELATE_BLOCKS` in `my_secrets.py` sets how coarse the picture is: the number of blocks
along the frame's long side, so `128` gives a 128×72 grid at 16:9 and `32` a 32×18 one. It is
`128` since 2026-10-01 22:59, and was `32` before that. ffmpeg averages each frame
down to that grid, scales it back up with nearest-neighbour so that every block is one solid
colour, and only then draws the timestamp. Apart from the timestamp, YouTube never receives
anything finer than the blocks. Fewer blocks means less detail. `None`, `0` or leaving the
line out turns it off. Change it like any other setting, with one restart.

The setting counts blocks, not pixels, so the level of detail stays the same if `RESOLUTION`
changes. That also means the resolution could go back up without adding detail. At 360p, for
example, the timestamp would cover about a third of the width instead of three quarters, and
each block would arrive 5 px wide at 128 blocks (20 px at 32) rather than 2, so the player's
upscaling would blur its edges less. That has not been tried, and would probably cost some
upload; the stream is still at 144p.

The same 144p frame at three levels, enlarged with smoothing the way a player shows the 144p
rendition:

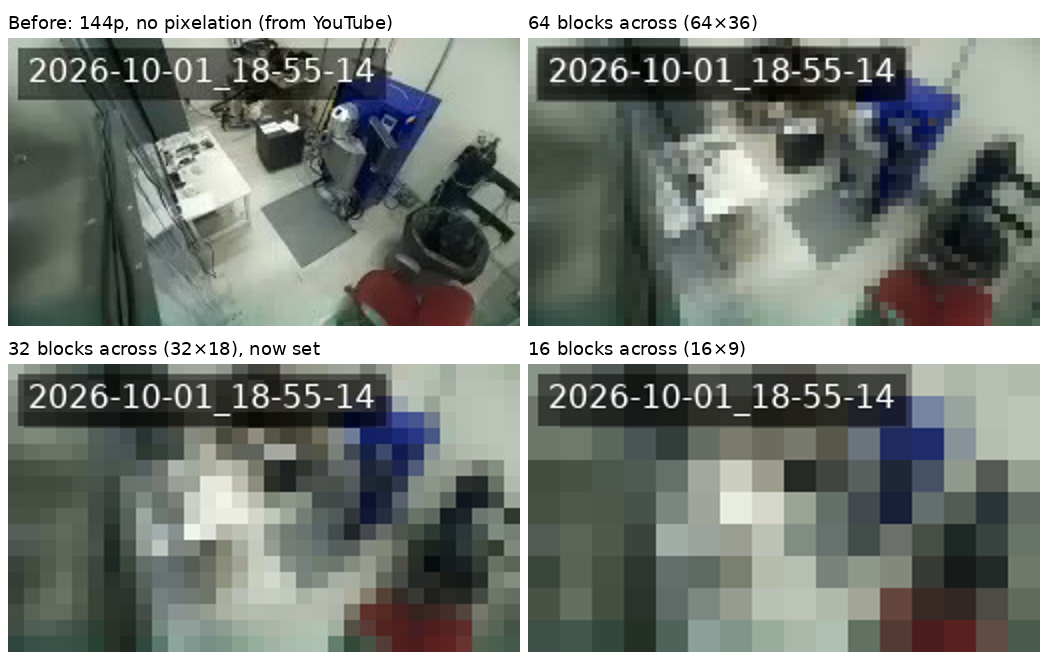
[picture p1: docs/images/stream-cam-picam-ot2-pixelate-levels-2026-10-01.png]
One 144p frame of the atomizer room unpixelated, and at 64, 32 and 16 blocks across


At 32, the layout of the room still shows (the blue cabinet, the white bench, the red chair),
but nothing on the bench or the cabinet can be made out. The three pixelated panels were made
offline from the "before" frame, with the same filter chain ffmpeg runs on the Pi:

```
scale=32:18:flags=area,format=yuv444p,scale=256:144:flags=neighbor,format=yuv420p,drawtext=…
```

- `area` averages every pixel in a block, rather than picking one.
- The grid is held as 4:4:4. In the stream's 4:2:0, colour is stored at half resolution, so
  each colour would span 2×2 blocks and bleed across their edges.
- It runs after any rotation, so the blocks line up with the streamed frame, and before
  `drawtext`, so the timestamp stays readable to people and to tesseract.

**Since 22:59 the level is 128, between plain 144p and 64.** The same frame, made the same
way, with the timestamp drawn as the Pi draws it:

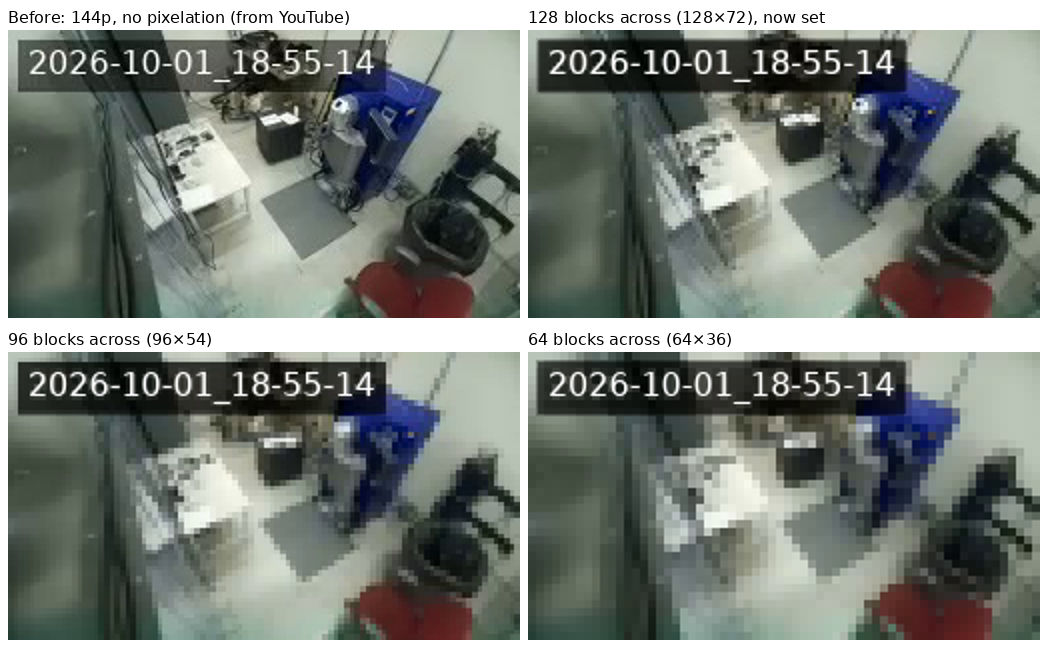
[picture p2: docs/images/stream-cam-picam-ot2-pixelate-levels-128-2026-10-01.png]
The same 144p frame unpixelated, and at 128, 96 and 64 blocks across


At 128 the room reads plainly, but the things on the bench and the cabinet are only shapes,
with no labels or fine edges. In log terms it is halfway, a block of 2×2 px against 1 px
unpixelated and 4×4 px at 64. It is also the only level between those two whose blocks are
whole pixels. Square blocks that tile 256×144 exactly need a side that divides both 256 and 144,
which leaves 1, 2, 4, 8 and 16 px, i.e. levels 256 (no change), 128, 64, 32 and 16. Any other
value works, but nearest-neighbour then makes the blocks uneven: at 96 (96×54) they are 2.67 px
on average, so they come out 2 or 3 px wide, which barely shows once a player has scaled the
picture up.

The lines added to `my_secrets.py` at 19:55; the value is `128` since 22:59:

```python
# Pixelation setting (optional)
# Averages the picture into this many solid blocks along its long side, so
# only coarse shapes and movement show (32 gives 32x18 at 16:9). Applied
# before the timestamp overlay, which stays sharp. Counted in blocks rather
# than pixels, so changing RESOLUTION keeps the same level of detail.
# Like TIMESTAMP_OVERLAY, it requires re-encoding.
# Set to None or 0 for a sharp picture.
PIXELATE_BLOCKS = 32
```

<details>
<summary>The <code>device.py</code> change, against the Pi's previous local version</summary>

```diff
--- a/device.py
+++ b/device.py
@@ -22,6 +22,12 @@
 except ImportError:
     SENSOR_MODE = None
 
+# Optional setting; older my_secrets.py files may not define it.
+try:
+    from my_secrets import PIXELATE_BLOCKS
+except ImportError:
+    PIXELATE_BLOCKS = None
+
 # Resolution mappings for YouTube-compatible resolutions
 RESOLUTION_MAP = {
     "144p": (256, 144),
@@ -57,6 +63,7 @@
     framerate=15,
     timestamp_overlay=False,
     sensor_mode=None,
+    pixelate_blocks=None,
 ):
     """
     Starts the libcamera -> ffmpeg pipeline and returns two Popen objects:
@@ -75,6 +82,10 @@
             sensor mode. Some sensors (e.g. imx708) auto-select a
             center-cropped mode for small outputs, losing field of view;
             forcing the full-FOV binned mode avoids that.
+        pixelate_blocks: Optional number of blocks along the streamed
+            frame's long side (e.g. 32 gives 32x18 at 16:9). Each block
+            is one solid colour, so only coarse shapes and movement show.
+            The timestamp is drawn afterwards and stays sharp.
     """
     # Get the available camera command
     camera_cmd = get_camera_command()
@@ -136,6 +147,24 @@
             "transpose=2"
         )  # 90 degrees counter-clockwise (270 clockwise)
 
+    # Pixelate after rotating, so the blocks line up with the streamed frame,
+    # and before the timestamp, so the timestamp stays sharp. Average down to
+    # the block grid, then scale back up with nearest-neighbour. The grid is
+    # held as 4:4:4 so each block keeps its own colour; in 4:2:0 the colour
+    # would be shared by 2x2 neighbouring blocks.
+    if pixelate_blocks:
+        if rotation in (90, 270):
+            out_width, out_height = height, width
+        else:
+            out_width, out_height = width, height
+        block = max(out_width, out_height) / pixelate_blocks
+        grid_width = max(1, round(out_width / block))
+        grid_height = max(1, round(out_height / block))
+        video_filters.append(
+            f"scale={grid_width}:{grid_height}:flags=area,format=yuv444p,"
+            f"scale={out_width}:{out_height}:flags=neighbor,format=yuv420p"
+        )
+
     # Add timestamp overlay if enabled
     # Format: YYYY-MM-DD_HH-MM-SS. ffmpeg's localtime evaluates per-frame,
     # so the overlay updates once per second at typical framerates.
@@ -313,6 +342,15 @@
             f"Must be a positive integer (e.g., 15, 24, 30)"
         )
 
+    # Validate pixelation
+    if PIXELATE_BLOCKS is not None and (
+        not isinstance(PIXELATE_BLOCKS, int) or PIXELATE_BLOCKS < 0
+    ):
+        raise ValueError(
+            f"Invalid PIXELATE_BLOCKS '{PIXELATE_BLOCKS}'. "
+            f"Must be a positive integer (e.g., 32), or 0 or None for none"
+        )
+
     # For 90/270 rotation, output is portrait (swapped dimensions)
     if CAMERA_ROTATION in (90, 270):
         output_width, output_height = height, width
@@ -328,6 +366,10 @@
     print(f"Using frame rate: {FRAME_RATE} fps")
     print(f"Sensor mode: {SENSOR_MODE or 'auto'}")
     print(f"Timestamp overlay: {'enabled' if TIMESTAMP_OVERLAY else 'disabled'}")
+    if PIXELATE_BLOCKS:
+        print(f"Pixelation: {PIXELATE_BLOCKS} blocks along the long side")
+    else:
+        print("Pixelation: off")
 
     # End previous broadcast and start a new one via Lambda
     end_previous_broadcast()
@@ -354,6 +396,7 @@
             FRAME_RATE,
             TIMESTAMP_OVERLAY,
             sensor_mode=SENSOR_MODE,
+            pixelate_blocks=PIXELATE_BLOCKS,
         )
         print("Stream started")
         interrupted = False
```

</details>

Like the `--flush` fix, this is only on this Pi. It would apply unchanged to any picam, and is
worth upstreaming to `ac-training-lab` with the rest of the local patch.

### Renaming the workflow

The Lambda ([`vertical-cloud-lab/streamingLambda`](https://github.com/vertical-cloud-lab/streamingLambda/blob/05eb749/chalicelib/ytb_api_utils.py))
matches on `WORKFLOW_NAME` twice per start. Both matches are case-insensitive substring
matches:

- `end` completes every live broadcast whose *title* contains the name.
- `create` adds the new broadcast to the first playlist whose *title* contains the name. It
  creates `"<name> Livestreams Playlist"` only if no title does.

That has two consequences for a rename:

- **End the old name's broadcast yourself.** On start, the device only ends broadcasts that
  match the new name. Broadcasts are created with `enableAutoStop` off, so without this step
  the old one would sit "live" with no video coming in. Stop the service, end the old
  broadcast with the device's own call, then start the service again:

  ```bash
  cd ~/ac-training-lab/src/ac_training_lab/picam
  venv/bin/python -c "from device import call_lambda; call_lambda('end', 'picam-ot2', 'OT-2')"
  ```

- **A name that looks unused may still match a playlist.** The channel's Playlists tab, and
  yt-dlp's listing of it, leave some public playlists out. The atomizer one is among them.
  A fragment also matches: `doser` would put broadcasts in the powder doser's playlist. The
  complete list is `playlists.list(mine=True)` with the channel's own credentials, which is
  what the Lambda uses.

### Change log

| When (MDT) | Change | Why |
| --- | --- | --- |
| 2026-10-01 17:01 | `RESOLUTION` `"720p"` → `"240p"`, then one restart of `device.service` | [#250](https://github.com/vertical-cloud-lab/byu-vcl/issues/250) |
| 2026-10-01 17:38 | `WORKFLOW_NAME` `"OT-2"` → `"Atomizer"` and `FRAME_RATE` `10` → `2`. Stopped the service, ended the OT-2 broadcast `KhqPemW8hhc` [by hand](#renaming-the-workflow), started it | [#252](https://github.com/vertical-cloud-lab/byu-vcl/pull/252#issuecomment-5942678722) |
| 2026-10-01 17:44 | `WORKFLOW_NAME` `"Atomizer"` → `"atomizer"`, to match the existing playlist's title and `powder doser`. `device.py` gains `-r FRAME_RATE`. `reset-failed`, then one restart | ffmpeg was sending 1.5 fps, see [above](#changing-a-setting) |
| 2026-10-01 18:52 | `RESOLUTION` `"240p"` → `"144p"`. `device.py` gains `rpicam-vid --flush` and ffmpeg `-flags low_delay`. One restart | [#252](https://github.com/vertical-cloud-lab/byu-vcl/pull/252#issuecomment-5943385687): 144p, and the overlay was jumping several seconds at a time |
| 2026-10-01 19:55 | `PIXELATE_BLOCKS = 32` added to `my_secrets.py`, and `device.py` gains the [pixelation](#pixelation) filter. One restart | [#252](https://github.com/vertical-cloud-lab/byu-vcl/pull/252#issuecomment-5944068559): pixelate on our side, so the stream shows what is happening without much detail |
| 2026-10-01 21:00 | Scheduled reboot, the first since these changes. It came back as configured, see [below](#32--128-blocks) | |
| 2026-10-01 22:59 | `PIXELATE_BLOCKS` `32` → `128`. One restart | [#252](https://github.com/vertical-cloud-lab/byu-vcl/pull/252#issuecomment-5945824243): a level between plain 144p and 64 blocks |

#### 720p → 240p

Measured on either side of that change. The "before" figures are averages over the 720p
pipeline's 3 h 15 min run, and the "after" figures cover its first 5 minutes:

| | 720p (before) | 240p (after) |
| --- | --- | --- |
| `rpicam-vid` output | 1280×720 | 426×240 |
| ffmpeg CPU (of 400 %) | 111 % | 23 % |
| ffmpeg memory (of 415 MB) | 31 % | 18 % |
| Load average, 1 min | 1.29 | 0.36 |
| SoC temperature | 61.8 °C | 51.5 °C |
| Upload to YouTube | 2.54 Mbit/s | 0.29 Mbit/s |
| Renditions YouTube serves | up to 1280×720 (format 232) | 426×240 (229) and 256×144 (269) |
| Broadcast | [`3zjB1Q9Je_o`](https://www.youtube.com/watch?v=3zjB1Q9Je_o) (ended by the restart) | [`KhqPemW8hhc`](https://www.youtube.com/watch?v=KhqPemW8hhc) |

Upload is RTMP bytes acknowledged by YouTube, read with `ss -tin`, which is the counter
the watchdog also uses. That was 3.72 GB over the 720p socket's life, and 2.14 MB over
60 s at 240p. The Wi‑Fi signal was −61 dBm before the change. The renditions are from `yt-dlp -F`, run on
the other stream-cam Pi because YouTube refuses player extraction from a CI runner. The
watchdog logged no failed checks after the restart.

The view and overlay are the same in both, with the full field of view kept at 240p:

| 720p, before | 240p, after |
| --- | --- |
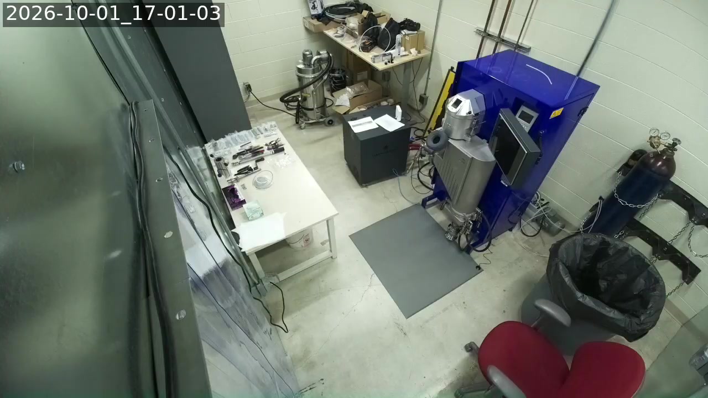
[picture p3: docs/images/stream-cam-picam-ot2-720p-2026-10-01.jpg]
720p frame of the atomizer room
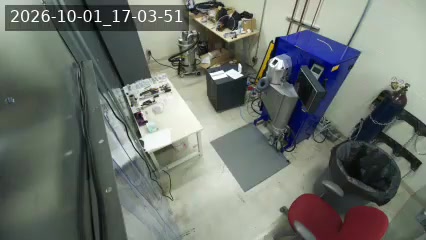
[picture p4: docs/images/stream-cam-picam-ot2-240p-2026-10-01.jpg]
240p frame of the atomizer room
|  |  |

#### 10 fps → 2 fps, and the `atomizer` workflow

Both columns are at 240p. The 10 fps figures average over that pipeline's first 35 minutes,
and the 2 fps ones over its first 3:

| | 10 fps (before) | 2 fps (after) |
| --- | --- | --- |
| ffmpeg output | 10 fps, keyframe every 20 frames | 2 fps, keyframe every 4 frames (2 s in both) |
| ffmpeg CPU (of 400 %) | 23 % | 12 % |
| `rpicam-vid` CPU | 5.0 % | 1.2 % |
| SoC temperature | 49.4 °C | 46.2 °C |
| Upload to YouTube, over 60 s | 0.30 Mbit/s | 0.18 Mbit/s |
| Broadcast | [`KhqPemW8hhc`](https://www.youtube.com/watch?v=KhqPemW8hhc), workflow `OT-2` | [`Lf4QFrrJ-lA`](https://www.youtube.com/watch?v=Lf4QFrrJ-lA), workflow `atomizer` |

Upload falls less than the frame rate does because the keyframe interval stays at 2 s, so at
2 fps one frame in four is a keyframe. ffmpeg's own counter read 439 frames in 219.5 s,
i.e. 2.0 fps. YouTube still serves 30 fps renditions (`229` and `269`), and repeats each
picture to fill them. The watchdog logged no failed checks after either restart.

That 2.0 fps was not 2 new pictures a second. ffmpeg met its rate by repeating frames, and the
overlay jumped 3–4 s at a time; see [The overlay that skipped seconds](#the-overlay-that-skipped-seconds).
A check made at the time compared consecutive decoded frames from YouTube and reported a new
picture every 0.5 s. It was wrong: re-encoding makes a repeated picture differ slightly from the
last, so comparing pixels cannot tell a repeat from a new frame. Reading the overlay can.

The intermediate broadcast [`TZ79Tej1hHY`](https://www.youtube.com/watch?v=TZ79Tej1hHY)
(17:38–17:44, titled *Atomizer …*) is the one that went out at 1.5 fps.

**The atomizer playlist already existed.** *atomizer Livestreams Playlist* (`PLeosQpHvsjiY`,
public) was made for this camera's move into the atomizer enclosure on 2026-09-29. Its
description says so, but it is missing from the channel's Playlists tab. The Lambda matched
the new name to it, so broadcasts now go straight there. Every OT-2 broadcast from
2026-09-29 15:27 UTC to `KhqPemW8hhc` was already in it. The Pi's journal shows the Lambda
filed each of them into the OT-2 playlist, so something else moved them. `KhqPemW8hhc` was
moved within 40 minutes of its creation. Nothing on either stream-cam Pi does that (no cron
jobs or timers, no playlist code), so it is somewhere else, or done by hand. With the rename
it has nothing left to move.

**The archive tooling assumes 720p.** `wireless-color-sensor/ot2/stream_grab_pi.py` asks
yt-dlp for format `232` (720p), and so does `~/ytframes/grab.py` on the other stream-cam Pi.
Broadcasts from this camera after 2026-10-01 23:01 UTC do not have that format. Their top
rendition is `229` (426×240), which after 2026-10-02 00:53 UTC is YouTube's upscale of the
144p feed; `269` (256×144) is the native one. `frames_from_stream.py`'s `OVERLAY_CROP` likewise
assumes the size of the 720p overlay. Both still work on the earlier 720p archives, such as the
2026-09-09 colour session. At 2 fps a frame grabbed at a given offset can be up to 0.5 s old,
and on this camera's 2 fps broadcasts before 2026-10-02 00:53 UTC the overlay is not a
reliable clock. From 2026-10-02 01:56 UTC the picture is [pixelated](#pixelation) but the
overlay is not: 32×18 blocks until 04:59 UTC, and 128×72 after that.

#### 240p → 144p

Both columns are at 2 fps under `atomizer`, and both were measured the same way, over 60 s,
about an hour into the 240p pipeline and 2 minutes into the 144p one:

| | 240p (before) | 144p (after) |
| --- | --- | --- |
| ffmpeg output | 426×240, 2 fps | 256×144, 2 fps |
| Camera frames ffmpeg dropped, and copies it sent instead | 2,892 and 2,893 of 8,144, over the whole 68 min | none in 2,989, the first 25 min |
| ffmpeg CPU (of 400 %) | 12.3 % | 9.5 % |
| `rpicam-vid` CPU | 1.1 % | 1.1 % |
| ffmpeg memory (RSS) | 67 MB | 61 MB |
| SoC temperature | 46.0 °C | 45.8 °C |
| Upload to YouTube | 0.18 Mbit/s | 0.07 Mbit/s |
| Renditions YouTube serves | `229` (426×240), `269` (256×144) | the same two; `229` is now an upscale |
| Broadcast | [`Lf4QFrrJ-lA`](https://www.youtube.com/watch?v=Lf4QFrrJ-lA) (ended by the restart) | [`osNAv6qmots`](https://www.youtube.com/watch?v=osNAv6qmots) |

The 144p column also has `--flush` and `low_delay`, described next. Neither adds work:
`--flush` changes when the camera's output leaves, and `low_delay` how ffmpeg schedules decoding.

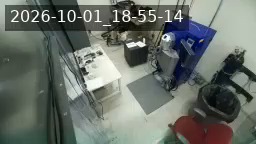
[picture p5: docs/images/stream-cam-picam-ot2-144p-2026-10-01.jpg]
144p frame of the atomizer room, from YouTube's 269 rendition


#### The overlay that skipped seconds

At 2 fps the overlay stood still for 3–4 s and then jumped. In 60 s of the live 240p rendition,
read frame by frame with tesseract, it showed 21 distinct times; 15 of the 20 steps between
them were 3 or 4 s. In 60 s at 144p after the fix it shows every second, about 2 frames each.
Below, one frame every 0.5 s from each sample, decoded in order from YouTube's HLS segments:

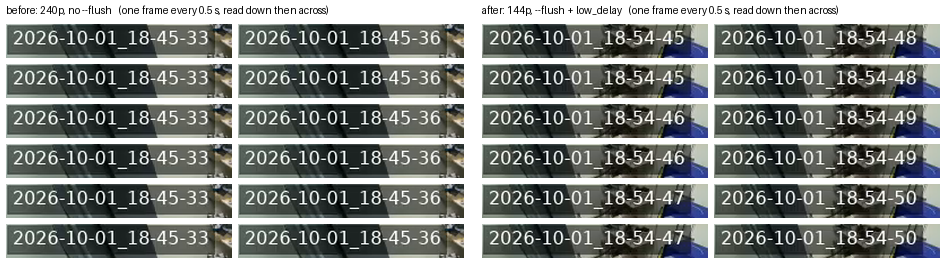
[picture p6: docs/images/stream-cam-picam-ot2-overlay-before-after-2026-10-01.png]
Overlay before and after: 240p holds 18-45-33 for 3 s then jumps to 18-45-36; 144p ticks every second, two frames per second


**Cause: `rpicam-vid` buffered its output.** With `-o -` it `fwrite`s each frame to stdout,
and stdout into a pipe is block-buffered unless `--flush` is given: nothing reaches ffmpeg
until 4 KB has piled up. At 240p and 2 fps a P-frame was about 700 bytes, so ffmpeg read 4096
bytes every 2.5–3.5 s, about six frames at once (read from `/proc/<pid>/io` over 20 s).

- drawtext's `localtime` is the wall clock when a frame passes the filter, not when the
  camera took it. Every frame of a batch got the same second, and the clock jumped by the gap.
- `-use_wallclock_as_timestamps` likewise gave a batch one timestamp, so `-vsync cfr` kept one
  frame per output slot and filled the empty slots with copies. Over the 68 minutes of the
  2 fps, 240p pipeline, ffmpeg dropped 2,892 of the camera's frames and duplicated 2,893 to
  replace them, about a third of everything. The picture froze along with the clock.

It went unnoticed at 720p and 10 fps, presumably because bigger, more frequent frames filled
the buffer within about a frame; frame sizes from then were not measured, and neither was the
240p, 10 fps stretch (17:01–17:38). At 144p a P-frame is about 100 bytes, so without the fix a
batch would have been about 40 frames, or 20 s.

**Fix: `--flush`, plus `-flags low_delay`.** `--flush` makes `rpicam-vid` flush after every
frame. On its own that stops the jumps but leaves the overlay late, because ffmpeg's H.264
decoder runs 5 frame threads on 4 cores and holds back 4 frames. `-flags low_delay`, as an
input option, turns frame threading off. What remains is one frame, since ffmpeg's parser
must see the start of the next frame before it can pass one on. Offline, a copy of this
pipeline (ffmpeg 7.1.5, as on the Pi) was fed 2 fps 256×144 H.264 frames of about 650 bytes
on a 4-core runner, and timed each frame from its write to the filter:

| `rpicam-vid` output | Overlay late by | Seconds skipped |
| --- | --- | --- |
| buffered (4 KB), as before | 2.5–5.5 s, varying | 6 of 10 |
| `--flush` | 2.50 s (5 frames) | none |
| `--flush` + `low_delay` | 0.50 s (1 frame) | none |

`-threads 1` in place of `low_delay` measured the same. On the Pi, ffmpeg now reads from the
pipe every 0.49–0.51 s, 40 times in 20 s. Its progress line has carried no `dup=` or `drop=`
since the restart, which it prints only once one of them is non-zero.

The overlay now trails the moment the camera took the frame by about one frame: 0.5 s at
2 fps. Earlier archives trailed by at least 5 frames (1 for the parser, 4 for the decoder
threads), which at 10 fps is 0.5 s, plus any batching. That is inferred from the same
mechanism, not measured on those archives.

`rpicam-vid`'s own log goes into the video pipe, not the journal. `device.py` starts it with
`stderr=subprocess.STDOUT`, which joins its stderr to the stdout that feeds ffmpeg. That is
why the journal has no camera messages. ffmpeg's H.264 parser skips text between frames, and
the journal shows no decode errors since 17:44.

#### Pixelated, 32 blocks

Both columns are at 144p and 2 fps, measured the same way over 60 s, about an hour into the
unpixelated pipeline and 3–4 minutes into the pixelated one:

| | 144p (before) | 144p, 32×18 blocks (after) |
| --- | --- | --- |
| ffmpeg CPU (of 400 %) | 9.4 % | 9.5 % |
| `rpicam-vid` CPU | 1.1 % | 1.1 % |
| ffmpeg memory (RSS) | 61 MB | 62 MB |
| SoC temperature | 45.8 °C | 45.8 °C |
| Upload to YouTube | 0.072 Mbit/s | 0.030 Mbit/s |
| Broadcast | [`osNAv6qmots`](https://www.youtube.com/watch?v=osNAv6qmots) (ended by the restart) | [`m_ITxTwPlrA`](https://www.youtube.com/watch?v=m_ITxTwPlrA) |

The upload more than halves, because solid blocks compress well. The two extra scales at
256×144 cost no measurable CPU. The startup log records the setting as `Pixelation: 32 blocks
along the long side`. ffmpeg's progress line showed no `dup=` or `drop=` over its first 506
frames (about 4 minutes; the journal only stores it in chunks), and the watchdog logged no
failed checks.

A frame of `m_ITxTwPlrA` from YouTube's 144p rendition (`269`), at its native size:

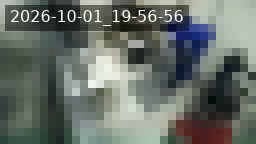
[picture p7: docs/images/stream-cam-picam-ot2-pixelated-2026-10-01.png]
Pixelated 144p frame of the atomizer room from YouTube, with a sharp timestamp


The overlay survives it. 62 s of that rendition was fetched through the other stream-cam Pi
and decoded at 2 fps, and tesseract read all 125 frames. Apart from the broadcast's first 7 s,
which held 19-56-23, it showed every second from 19-56-24 to 19-57-19, two frames each.

#### 32 → 128 blocks

**The 21:00 scheduled reboot came back as configured.** The first since the changes above, on
2026-10-01. The Pi booted at 21:00:14, and `device.service` started at 21:00:34 with `atomizer`,
144p, 2 fps and `Pixelation: 32 blocks along the long side`. Its start-up `end` call succeeded,
and it created [`bUV9kGK-Yh0`](https://www.youtube.com/watch?v=bUV9kGK-Yh0) in the atomizer
playlist. ffmpeg's `Output #0` line said 2 fps. Over that pipeline's whole run, 14,194 frames in
1 h 58 min, its progress line never showed `dup=` or `drop=`. The watchdog logged nothing.

Both columns are at 144p and 2 fps, measured the same way over 60 s, about 2 h into the
32-block pipeline and 5–6 minutes into the 128-block one:

| | 32×18 blocks (before) | 128×72 blocks (after) |
| --- | --- | --- |
| ffmpeg CPU (of 400 %) | 9.5 % | 9.9 % |
| `rpicam-vid` CPU | 1.1 % | 1.1 % |
| ffmpeg memory (RSS) | 57 MB | 62 MB |
| SoC temperature | 45.9 °C | 45.9 °C |
| Upload to YouTube | 0.030 Mbit/s | 0.061 Mbit/s |
| Broadcast | [`bUV9kGK-Yh0`](https://www.youtube.com/watch?v=bUV9kGK-Yh0) (ended by the restart) | [`GELJvjX_weo`](https://www.youtube.com/watch?v=GELJvjX_weo) |

Finer blocks leave more for the encoder, so the upload doubles, but it is still below the
unpixelated 0.072 Mbit/s. An earlier sample, 2–3 minutes in, gave the same upload and 10.0 % CPU.
The startup log reads `Pixelation: 128 blocks along the long side` and `Output #0 … 2 fps`.
ffmpeg's progress line showed no `dup=` or `drop=` over its first 506 frames. The watchdog
logged nothing.

A frame of `GELJvjX_weo` from YouTube's 144p rendition (`269`), at its native size:

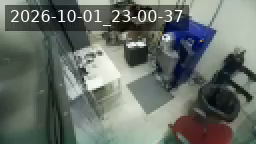
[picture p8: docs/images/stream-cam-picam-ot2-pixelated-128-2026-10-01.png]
Frame of the atomizer room from YouTube at 128×72 blocks, with a sharp timestamp


The overlay still keeps time. The broadcast's first 70 s of that rendition were fetched through
the other stream-cam Pi and decoded at 2 fps, and tesseract read all 139 frames. The first 7.5 s
held 22-59-54 as the broadcast started, as the 19:56 start did. After that the overlay showed
every second from 22-59-55 to 23-00-56, two frames each.

Older records for this Pi are not on `main` yet:

- the original setup: [#172](https://github.com/vertical-cloud-lab/byu-vcl/issues/172), `docs/ot2-stream-cam.md` on branch `claude/issue-172-20260731-0633`
- the NetworkManager ACD change: [#237](https://github.com/vertical-cloud-lab/byu-vcl/issues/237), branch `claude/issue-237-20260926-0939`
- copies of the watchdog: [#202](https://github.com/vertical-cloud-lab/byu-vcl/pull/202), `wireless-color-sensor/ot2/livestream-pi/`

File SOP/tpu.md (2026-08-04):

# 3D Printing Using TPU
## Bambu Studio
1. In Bambu Studio, select the three dots next to the TPU filament and edit to the following presets (with the orange reset symbol next to them):
   *    
   
   *    This causes better adhesion when printing small, vertical prints, minimizing 'wobble.'
1. If printing a tall, thin, or small object, make sure to generate a raft in Bambu Studio before slicing or use the Bambu Glue Stick on the print plate for better adhesion.
### Support Settings
1. If necessary, paint manual supports onto each part (MANUAL SUPPORTS VIDEO HERE).
1. If printing a tall object with thin TPU elements:
   *    Make sure to set support filament to PLA only FOR EACH OBJECT (this will prevent wobbling during printing).
   *    Change "Support/object xy distance" from 0.35 to 0.2 so the supports are close enough to have effect on such a small cross-section.
   Also, DENY any suggested preset adjustments from Bambu Studio that come from this decision:
   *    

1. Additionally, disable flushing TPU into supports:
   *    

1. Make sure to select 'On build plate only,' so supports are not built on the object being printed (unless there is no other possible orientation).

## Preparing the 3D Printer
1. If humidity is not below 8%, run a TPU dry cycle at 70-75&deg;C for 12hr or until below 8% humidity.
1. Clean Nozzle(s)
   *    Note: To switch active nozzle, click 'right' or 'left' on 3D printer, then wait for it to switch.
   *    Remove Heat Cover
   *    Heat Nozzle to 180&deg;C
   *    Use razor and paper towels to peel and wipe gummy material off nozzle. CAUTION: The nozzle is HOT; take care to avoid burns.
   *    Cool Nozzle to 0&deg;C
   *    Replace Heat Cover
1. Load the TPU (Make sure to do this step even if the TPU is already loaded; this prevents clogs.)
   *    On the 3D printer, select the roll of TPU and click "Load." Wait for the prompt to push the filament into the extruder.
   *    If TPU not loaded AND using TPU assist module:
        -    Feed the TPU through the loading tube at the back of the TPU AMS system until TPU touches the feed area of the TPU assist module.
        -    Press the right button to automatically feed the TPU down the tube and into the extruder.
   *    If TPU not loaded:
        -    Hand feed the TPU through the hole at the back of the printer labeled for TPU, through the loops where a PTFE tube normally sits, and push into the extruder.
        -    If extruder does not automatically sense filament and begin feeding, select 'Finished, continue."
   *    Else (if TPU is already loaded):
        -    Pass
   *    Follow any remaining instructions on the printer.
1. Brush any leftover filament purge from previous print jobs out of the waste chute.
1. Finally, slice and print the file like normal.

## Notes & Troubleshooting:
1. If the prints have too many bubbles, this is a humidity issue. Try printing at a drier temperature.
1. For thinner prints, if there appears to be 'wobble' in the print when using 100% PLA supports, this can usually be remedied by the TPU filament preset changes and additional supports on the edges of the part.
   When the min and max temperatures are too far apart, there can be 'skipping,' which causes wobble between 3D print layers as the filament takes extra time to adhere and misses the target point of adhesion.
1. When using generated models, make sure to **keep non-manifold edges** even if Bambu Studio gives an error message. Otherwise, essential geometry may be eliminated by Bambu Studio's 'auto-repair' feature.

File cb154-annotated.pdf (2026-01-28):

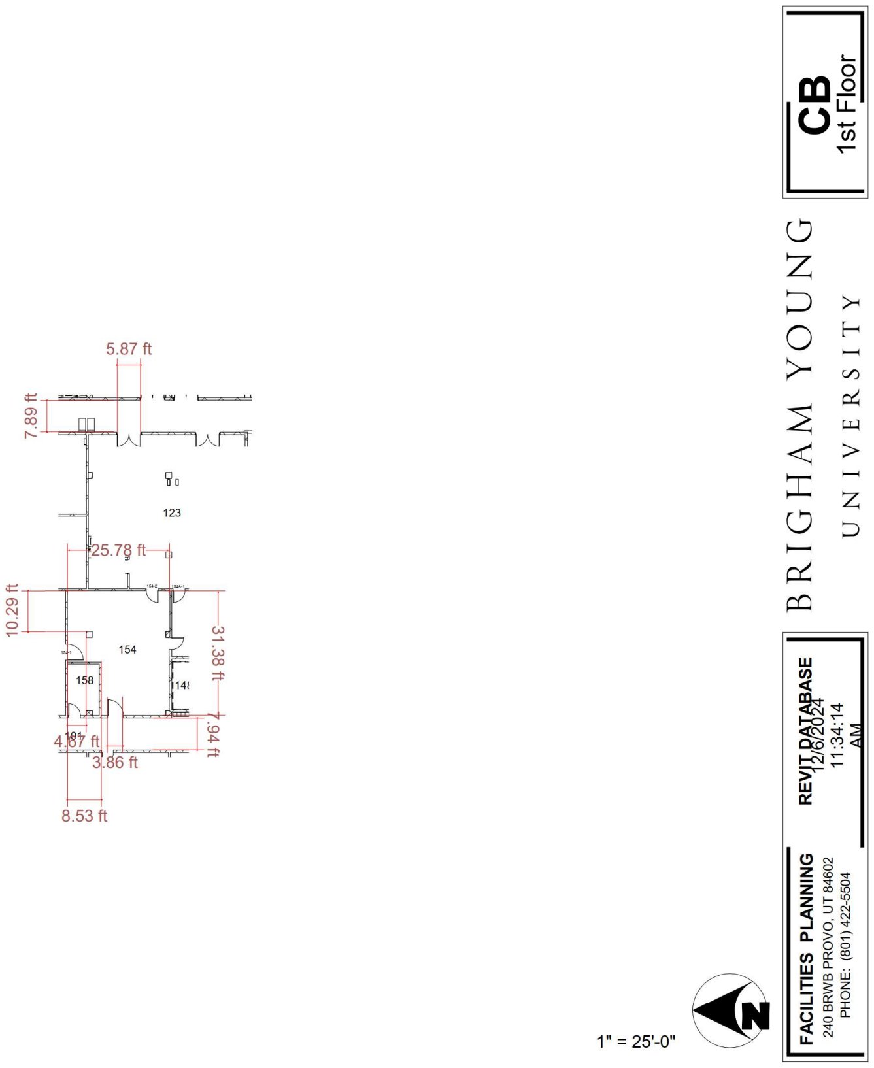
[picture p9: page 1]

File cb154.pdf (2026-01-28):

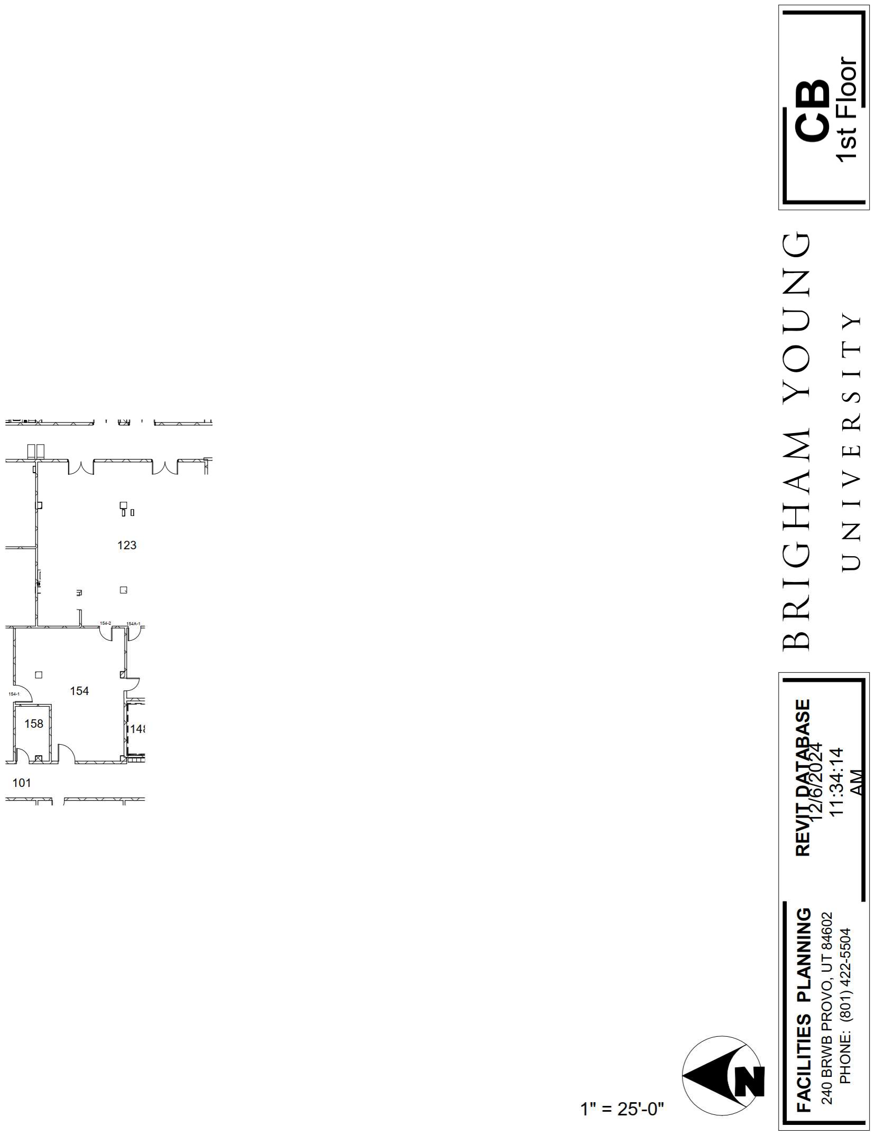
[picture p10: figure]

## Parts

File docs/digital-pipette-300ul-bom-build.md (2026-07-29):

# Digital Pipette (v2) redesigned down to 300 µL — BOM & build guide

A bill of materials and build guide for the Acceleration Consortium **Digital Pipette**, **rescaled
from its stock milliliter range down to a ~300 µL, disposable-tip, OT-2-P300-class head** for the
**CubXL** gantry.

> **Sources.** v1 (public CAD + firmware): [`ac-rad/digital-pipette`](https://github.com/ac-rad/digital-pipette)
> (CC-BY-4.0 hardware / MIT firmware), paper [10.1039/D3DD00115F](https://doi.org/10.1039/D3DD00115F).
> v2 (air-displacement + robotic tip exchange, ~$270, validated **0.2–10 mL** with BRAND 1–10 mL
> tips): [10.1039/D5DD00336A](https://doi.org/10.1039/D5DD00336A).
>
> **Important:** as published, **both versions are milliliter-scale.** The public repo CAD
> (`platform.stl`, `holder.stl`, `cover.stl`) is built around a **10 mL NORM-JECT syringe**. There
> is no released 300 µL variant — this document specifies the redesign, with the geometry math to
> pick the syringe and confirm resolution.

## Why it needs a redesign, in one paragraph

The Digital Pipette is a **linear actuator pushing a syringe plunger**. Volume per unit stroke is
fixed by the **syringe barrel cross-section**. The stock 10 mL syringe (~15.9 mm bore) moves ~0.5 µL
for every micron of stroke — far too coarse to meter 300 µL accurately. To hit 300 µL you **swap in
a much smaller syringe** (1 mL or 0.5 mL) and reprint the plunger holder + syringe cradle to that
smaller barrel. Everything else (actuator, controller, wiring) carries over. To get disposable-tip,
contamination-free operation like OT-2, run it as an **air-displacement** head (syringe = air
piston) driving a **standard 300 µL tip**, and add a **tip stripper**, which is the essence of the
v2 upgrade.

## The geometry: picking the syringe

Volume displaced `V = A · s`, where `A = π/4 · d²` (barrel bore area) and `s` = plunger stroke.
The actuator is an **Actuonix L16-100-63-6-R**: **100 mm** stroke, 6 V, ~50 N at the 63:1 ratio,
built-in position feedback. Assume a conservative **closed-loop positioning step of ~0.1 mm**.

| Syringe (NORM-JECT) | Bore d | Area A | Stroke for 300 µL | Full-scale volume at 100 mm | Resolution @ 0.1 mm step |
|---|---:|---:|---:|---:|---:|
| **1 mL** | ~4.7 mm | ~17.3 mm² | **~17 mm** | (barrel ≈ 58 mm travel = 1 mL) | ~**1.7 µL** (0.58% of 300 µL) |
| **0.5 mL** | ~3.3 mm | ~8.4 mm² | **~36 mm** | (barrel travel gives ~0.5 mL) | ~**0.84 µL** (0.28% of 300 µL) |
| 10 mL (stock) | ~15.9 mm | ~199 mm² | ~1.5 mm | 10 mL | ~20 µL (6.7%) — too coarse |

**Recommendation: a 1 mL syringe** as the default (300 µL uses a comfortable ~17 mm of the 100 mm
stroke, leaving room for an air gap and blow-out), or a **0.5 mL syringe** if you want finer
resolution and don't need >~450 µL. Both bring per-step resolution below 1% of 300 µL, in reach of
ISO-8655 accuracy after gravimetric calibration. Force is a non-issue: 300 µL air displacement needs
far less than the actuator's ~50 N.

## What changes vs. the stock (v1) design

| Aspect | Stock v1 | 300 µL redesign |
|---|---|---|
| Syringe | NORM-JECT 10 mL | **NORM-JECT 1 mL** (or 0.5 mL) |
| `holder.stl` (plunger holder) | 10 mL plunger tip | **Reprint** to grip the 1 mL plunger |
| `cover.stl` + `platform*.stl` | 10 mL barrel cradle | **Reprint/scale** to the 1 mL barrel OD & flange |
| Front end | Luer syringe, direct liquid | **Air-displacement**: printed nozzle/cone that a **300 µL disposable tip** press-fits onto, air-coupled to the syringe (short tubing or direct Luer) |
| Tip removal | none (v1) | **Fixed stripper collar** the nozzle retracts through (v2-style robotic tip exchange) |
| Calibration | steps↔mm↔mL for 10 mL | Re-derive steps↔µL for the new bore (see below) |

The Fusion 360 sources (`design/f3d/*.f3d`) are the right place to make these edits — the barrel
pocket in `platform`/`cover` and the plunger cup in `holder` are parametric to the syringe you drop
in.

## Bill of materials

### A. Actuation & control (carries over from v1)

| Item | Qty | Spec | ~Cost |
|---|---:|---|---:|
| **Actuonix L16-100-63-6-R** linear actuator | 1 | 100 mm stroke, 6 V, position feedback — [actuonix.com](https://www.actuonix.com/l16-100-63-6-r) | $70–100 |
| DC 6 V actuator power supply | 1 | Actuonix DC PSU or any 6 V supply | $15–25 |
| Microcontroller | 1 | Arduino Uno (stock) / Pi Pico / ESP32; runs `pipette.ino` | $10–25 |
| Breadboard/PCB, jumper + alligator wires, solder | set | Basic circuit build | $10 |
| M3 screws & nuts | 3× M3-10 mm, 1× M3-20 mm | Per v1 BOM | $3 |

> On the CubXL you can drive the actuator from your existing controller instead of a dedicated
> Arduino; the L16-R takes a simple position command (PWM/analog with the -R feedback line, or via
> the Actuonix control approach in `pipette.ino`).

### B. Metering front end (the 300 µL change)

| Item | Qty | Spec | ~Cost |
|---|---:|---|---:|
| **NORM-JECT 1 mL** Luer syringe (default) | 1+ | ~4.7 mm bore; 0.5 mL optional for finer resolution | ~$1 ea |
| Reprinted `holder.stl` (plunger cup, 1 mL) | 1 | Scaled to 1 mL plunger | filament |
| Reprinted `cover.stl` + `platform*.stl` (1 mL cradle) | set | Scaled to 1 mL barrel | filament |
| Printed **tip nozzle/cone** for 300 µL tips | 1 | Air-displacement front end; press-fit for universal 300 µL tips | filament |
| Silicone/PTFE tubing (if syringe is remote-mounted) | short | Air-couple syringe → nozzle | $3 |
| **300 µL disposable tips** + rack | 1 box | Universal-fit / Opentrons-style | $10–30 |

### C. Tip exchange (v2 capability)

| Item | Qty | Spec | ~Cost |
|---|---:|---|---:|
| Printed **fixed stripper plate/collar** | 1 | Bracket the nozzle retracts up through to shear off the used tip (North/N9-style, no extra motor) | filament |
| (Alt.) motorized ejector | 1 | Only if you want active eject instead of a passive stripper | $10–20 |

**Redesign total: ≈ $110–170** (actuator dominates), well inside the $100–300 target.

## Build steps

1. **Choose the syringe** (1 mL default) and **edit the CAD** (`design/f3d/holder.f3d`,
   `platform*.f3d`, `cover.f3d`) so the plunger cup and barrel cradle match its dimensions. Export
   new STLs.
2. **Print** the resized holder, platform, cover, plus the **tip nozzle** and the **stripper plate**
   (PETG/ABS for durability).
3. **Set the actuator zero.** Before assembly, use the microcontroller + `pipette.ino` to drive the
   L16 to a known reference and confirm the 100 mm stroke, exactly as in the v1 instructions.
4. **Assemble** per the v1 guide: plunger holder → actuator (short M3), actuator → platform (M3
   long + shipped brackets), syringe seated between platform and cover, plunger cup on the syringe
   plunger.
5. **Fit the front end.** Air-couple the syringe outlet to the printed nozzle (direct Luer or short
   tubing). Press a 300 µL tip onto the nozzle and verify a sealed air path.
6. **Mount to the CubXL carriage** and position the **stripper plate** at a fixed point so the
   nozzle can retract up through it to eject a tip; the tip rack goes within XY reach for pickup.
7. **Wire** the actuator to your controller (or the stock Arduino circuit — remember to tie
   Arduino GND and the 6 V supply GND together, per the v1 README).
8. **Calibrate gravimetrically.** Command increments of stroke, weigh dispensed water (ρ≈1 g/mL),
   and fit **steps→µL** for the new bore. Target ISO-8655-2 tolerances at 300 µL; expect ~1.7 µL
   theoretical resolution with a 1 mL syringe at 0.1 mm steps, better with 0.5 mL.
9. **Validate** across the working range (e.g. 50/150/300 µL): report systematic error and CV like
   the v2 paper (which reported −0.49% to −0.10% error / 0.10–0.58% CV at its mL scale).

## Open risks / notes

- **Resolution vs. accuracy.** The L16's real closed-loop repeatability may be coarser than the
  assumed 0.1 mm; if 300 µL accuracy misses ISO-8655, step down to the **0.5 mL** syringe or a
  higher-gear-ratio actuator (finer µm/step) at the cost of speed.
- **Air-displacement dead volume.** Keep the tubing between syringe and tip short and rigid;
  compliant/large air volumes degrade accuracy and add lag.
- **This is a redesign, not a reprint.** Unlike FINDUS (which uses a commercial pipette off the
  shelf), the accuracy here must be **re-established by your own calibration** — budget time for the
  gravimetric validation loop. The upside is a fully open, ~$150, Jubilee-ready head with disposable
  300 µL tips.

## Sources

- Digital Pipette v1 (CAD/firmware): [`ac-rad/digital-pipette`](https://github.com/ac-rad/digital-pipette);
  paper [10.1039/D3DD00115F](https://doi.org/10.1039/D3DD00115F)
- Digital Pipette v2 (air-displacement + tip exchange, ~$270): [10.1039/D5DD00336A](https://doi.org/10.1039/D5DD00336A)
- Actuator: [Actuonix L16-100-63-6-R](https://www.actuonix.com/l16-100-63-6-r)
- Syringe bore dimensions: NORM-JECT / Air-Tite Luer syringe datasheets
- Jubilee integration precedent: Pelkie et al. 2025, [10.26434/chemrxiv-2025-zhkrf](https://doi.org/10.26434/chemrxiv-2025-zhkrf)

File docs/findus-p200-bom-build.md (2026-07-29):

# FINDUS P200 pipette subassembly — BOM & build guide

A practical bill of materials and build guide for extracting the **FINDUS pipette arm** (the
motorized "robot thumb" that drives a standard manual **P200 / 20–200 µL** pipette) and mounting it
as a tool on the **CubXL** custom Cartesian gantry.

> **Source of truth.** FINDUS = Barthels et al., *SLAS Technology* 2020, 25(2) 190–199,
> [10.1177/2472630319877374](https://doi.org/10.1177/2472630319877374). All CAD (FreeCAD `.FCStd`
> + meshed `.stl`), firmware, and the Python driver are in
> [`FBarthels/FINDUS`](https://github.com/FBarthels/FINDUS) (GPL-3.0). Numbers below are read
> directly out of that repo — e.g. `source code/findus.py` documents **200 µL = 16 mm plunger
> travel** and the GT2/pulley step math.

## What the subassembly actually is

FINDUS does **not** contain a custom air-displacement head. It holds an **off-the-shelf manual
single-channel pipette** (a P200-class pipette, 20–200 µL) in a printed casing and presses its
plunger button with a **stepper-driven rack-and-pinion "thumb."** That means:

- **Accuracy/precision come from the commercial pipette itself** (< 0.3% relative error reported),
  and you use **standard 200 µL disposable tips** — exactly the OT-2-like behavior we want.
- The only things you build are the **motorized thumb**, the **pipette-holding casing**, and a
  passive **tip-changer (ejector) station**.
- Volume is set by driving the plunger a calibrated distance: **≈ 0.08 mm/µL** for a P200
  (16 mm of travel = 200 µL), vs 0.02 mm/µL for a P1000.

This is the cleanest open-source path to "P300-class disposable-tip pipetting on our own gantry":
adopt the arm, drop the FINDUS XYZ frame (the CubXL replaces it).

## Files to print (from `3D-models/pipette-arm/`)

| Printed part (STL) | Role |
|---|---|
| `Thumb_Casing (Meshed).stl` | Clamps the pipette body; the whole tool carrier |
| `Adapter (Meshed).stl` | Adapts the casing to the specific pipette body/collar (P200) |
| `Gear (Meshed).stl` + `Pinion (Meshed).stl` | Reduction gear + pinion driven by the stepper |
| `Gear_rack(Meshed).stl` + `Gear_Rack_Nut (Meshed).stl` | The linear "thumb" that presses the plunger |
| `Gear_Cover (Meshed).stl` | Gear guard |
| `Sliding_Bearing.FCStd` | Printed linear guide for the rack (export STL from FreeCAD) |

Reference-only (open in FreeCAD to check fit, not printed as-is):
`Assembly_Thumb.FCStd`, `Step_Motor.FCStd`, and the exploded view `expl.png`.
The **`P1000_Adapter` / `P1000_Bolt` / `P1000_Bottom`** parts are the **alternate** set for a P1000
pipette — **skip them for the P200 build**.

Tip-eject station (from `3D-models/racks/`): `tip-changer-top/bottom`, `tip-changer-bolt`,
`tip-changer-shaft-fixer`, and `Tip-changer-mount.png` for placement. Tip/well racks
(`tip-rack`, `96-well-rack`, `eppi-rack`) are optional if you use your own labware.

## Bill of materials

### A. The pipette (the "consumable" spec target)

| Item | Qty | Spec / example | ~Cost |
|---|---:|---|---:|
| Manual single-channel pipette, **20–200 µL (P200)** | 1 | Eppendorf Research plus, Gilson PIPETMAN P200, or generic; plunger travel ≈ 16 mm | $30–150 |
| 200 µL disposable tips + tip rack | 1 box | Standard universal-fit tips | $10–30 |

Pick the pipette **first** and confirm the printed `Adapter`/`Thumb_Casing` fits its body diameter
and plunger geometry — FINDUS's casings were modeled around a specific pipette and usually need a
small scale/offset tweak in FreeCAD for a different brand.

### B. Actuation (the motorized thumb)

| Item | Qty | Spec | ~Cost |
|---|---:|---|---:|
| **NEMA 11 stepper**, 1.8°/200-step, ~**6 N·cm** holding torque | 1 | Drives the pinion → rack → plunger | $15–20 |
| **DRV8825** stepper driver (Pololu breakout) | 1 | Per FINDUS schematic `findus.sch`; 32× microstepping | $3–6 |
| Printed pinion, gear, gear-rack, rack-nut, sliding bearing | set | From `pipette-arm/` STLs | filament ~$3 |
| Steel shaft/rod for the sliding bearing + pinion axle | 1–2 | ~3–5 mm rod, cut to length | $3 |
| M3 screws/nuts + heat-set inserts | ~10 | Assembly hardware | $5 |

### C. Control electronics

| Item | Qty | Spec | ~Cost |
|---|---:|---|---:|
| Microcontroller | 1 | Stock FINDUS uses an **ESP8266 (ESP-12)** running `findus.ino` (Wi-Fi AP + HTTP API). **On the CubXL**, drive the pipette axis from your existing motion controller instead (e.g. a Duet/RRF **E-axis**, or an extra DRV8825 on your MCU). | $0–10 |
| 12 V PSU for the driver | 1 | Sized for the stepper; shareable with the gantry supply | $0–15 |
| Endstop / limit switch for plunger home | 1 | To home the thumb to a repeatable zero | $2 |

### D. Tip ejection

| Item | Qty | Spec | ~Cost |
|---|---:|---|---:|
| Printed **tip-changer station** | 1 | `racks/tip-changer-*` — a fixed fixture the pipette pushes into to strip the used tip (see `remTip()` in `findus.py`) | filament ~$2 |

**Subassembly total (excluding the pipette): ≈ $35–70** plus the pipette ($30–150) and tips.
The full FINDUS workstation is "< $400"; the pipette arm alone is a small fraction of that.

## Calibration constants (straight from `findus.py`)

- **P200:** `200 µL ≈ 16 mm plunger travel` → **0.08 mm/µL** (≈ 43 steps/µL at the pipette axis).
- **P1000:** `1000 µL ≈ 19.9 mm` → 0.02 mm/µL (for reference).
- **XYZ belt axes** (not the pipette): GT2 belt (2 mm pitch) + 20-tooth pulley = 40 mm/rev;
  200 steps × 32 microsteps ÷ 40 mm = **160 steps/mm**. Reuse this only if you belt-drive an axis.
- Tip pick/eject positions are table-driven (`tip200`, `tip1000`, `tipbin` in `findus.py`) — retune
  the Z heights for the CubXL bed and your tip rack.

## Build steps

1. **Print** the `pipette-arm` set (Thumb_Casing, Adapter, Gear, Pinion, Gear_rack, Gear_Rack_Nut,
   Gear_Cover) and the `tip-changer` station. PETG/ABS recommended for the load-bearing thumb.
2. **Fit-check the casing** to your chosen P200 in FreeCAD; scale/offset the `Adapter` if needed so
   the pipette seats firmly and the rack lands square on the plunger button.
3. **Assemble the drive:** press the pinion onto the NEMA 11 shaft, mesh it with the printed gear,
   engage the gear on the rack, and slide the rack into the printed sliding bearing. The rack tip
   should contact the plunger button with a few mm of pre-travel headroom.
4. **Mount the pipette** in the Thumb_Casing/Adapter and bolt the stepper so the thumb's stroke
   covers the full 16 mm (P200) plunger travel plus the tip-eject over-stroke.
5. **Wire the stepper** to a DRV8825 (32× microstep) and to your controller — on the CubXL, add it
   as an extra stepper axis on your existing board (Duet E-axis or a spare DRV8825 on your MCU).
   You do **not** need the ESP8266 unless you want FINDUS's standalone Wi-Fi controller.
6. **Mount the tip-changer station** at a fixed, reachable spot on the CubXL bed (see
   `Tip-changer-mount.png`). Tip pickup = press the pipette onto a tip in the rack; ejection =
   drive into the tip-changer and retract (`getTip`/`remTip`).
7. **Home & calibrate:** set the plunger-home endstop as zero, then verify **16 mm = 200 µL**
   gravimetrically (weigh dispensed water, ρ≈1 g/mL) and adjust steps/µL to hit ISO-8655 tolerance.
8. **Drive it** from your gantry firmware, or adapt the FINDUS `findus.ino` + `findus.py` API if you
   keep the ESP8266.

## CubXL integration notes

- **Reuse the arm, drop the frame.** The CubXL is the XYZ system; you only need the `pipette-arm`
  (+ tip-changer). Mount the Thumb_Casing to your carriage/tool plate.
- **One extra motor axis.** The plunger is just another stepper — simplest is to run it as an
  E-axis on a Duet/RRF board (matches the Jubilee tool-changer path used elsewhere in this repo).
- **Volume class:** P200 tops out at 200 µL. For a true 300 µL, fit a **P300-class** manual pipette
  and re-derive mm/µL (the mechanism is identical; only the casing/adapter fit and calibration
  change). This is the smallest change to reach the 300 µL target with a commercial pipette's
  accuracy.

## Sources

- FINDUS paper: [10.1177/2472630319877374](https://doi.org/10.1177/2472630319877374)
- Repo (CAD, firmware, driver): [`FBarthels/FINDUS`](https://github.com/FBarthels/FINDUS) — GPL-3.0
- Calibration/step math: `source code/findus.py`; firmware: `source code/findus/findus.ino`;
  schematic: `findus.sch` (DRV8825 × 4, ESP-12)

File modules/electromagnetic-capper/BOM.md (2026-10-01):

# Bill of Materials — Electromagnetic Vial Capper/Decapper

Scoped to the capper/decapper module only (not the full PANDA-film platform).
Sources: [arXiv:2601.07043](https://arxiv.org/abs/2601.07043) §2 and the
[PANDA-BEAR BOM](https://github.com/BU-KABlab/PANDA-BEAR/blob/main/documentation/documents/bom.md) /
[Construction Guide](https://github.com/BU-KABlab/PANDA-BEAR/blob/main/documentation/Construction.md).
Prices are the PANDA-BEAR listed values (USD, mid-2026) — verify at order time.

## 1. Parts to procure (ME order)

| # | Item | Role | Part # | Vendor / Link | Qty | Est. Cost (USD) |
|---|---|---|---|---|-----|---|
| 1 | Electromagnet, 5 V 50 N (uxcell) | Cap pickup | 604267002199 | [Amazon B01N5OPUEC](https://www.amazon.com/dp/B01N5OPUEC) | 1 | 9.89 |
| 2 | IR break-beam sensor, 5 mm LEDs | Cap pickup/replace detection | 2168 | [Adafruit 2168](https://www.adafruit.com/product/2168) | 1 | 5.99 |
| 3 | Arduino Uno SMD R3 | Module control | A000073 | [DigiKey](https://www.digikey.com/en/products/detail/arduino/A000073/3476357) | 1 | 26.30 |
| 4 | Adafruit Proto Shield v5 | Driver circuitry | 2077 | [Adafruit 2077](https://www.adafruit.com/product/2077) | 1 | 9.95 |
| 5 | IRLZ44 logic-level MOSFET (kit) | Electromagnet switch | IRLZ44 | [Amazon B0CBKH4XGL](https://www.amazon.com/dp/B0CBKH4XGL) | 1 kit | 9.99 |
| 6 | 1N5819 Schottky flyback diode (kit) | Coil flyback protection | 1N5819 | [Amazon B079KG1TN2](https://www.amazon.com/dp/B079KG1TN2) | 1 kit | 7.99 |
| 7 | Resistor assortment (needs 200 Ω, 1 kΩ, 3 kΩ, 10 kΩ) | Gate/pull-down/sensor circuit | — | any (e.g., McMaster/Amazon assortment) | 1 kit | ~10 |
| 8 | 5 V DC power supply (≥2 A recommended) | Electromagnet power | — | any (e.g., [Adafruit 276](https://www.adafruit.com/product/276)) | 1 | ~8 |
| 9 | Jumper wires F–F, 200 mm ×40 | Wiring | 4447 | [Adafruit 4447](https://www.adafruit.com/product/4447) | 1 | 9.95 |
| 10 | Jumper wires M–M, 200 mm ×40 | Wiring | 4482 | [Adafruit 4482](https://www.adafruit.com/product/4482) | 1 | 9.95 |
| 11 | 20 mL clear VOA vials w/ septa caps | Stock vials the module services | 12-100-112 | [Fisher Sci](https://www.fishersci.com/shop/products/clear-voa-glass-vials-0-125in-septa/12-100-112) | 1 case | ~80 (case) |
| 12 | Sylgard 184 PDMS kit (base + curing agent — the "Silicone Elastomer Curing Agent" is what the paper calls the crosslinker) | Cap interior fill, 10:1 by weight | Sylgard 184 | [Electron Microscopy Sciences 24236-10](https://www.emsdiasum.com/sylgard-184-silicone-elastomer-kit) | 1 kit (1.1 lb) | ~60 |
| 13 | Steel discs (magnetic mild steel; size to the recessed cap top — verify dia./thickness against `cad/VialCap16mm.step`) | Magnetic pickup target on each cap | — | McMaster-Carr (e.g., low-carbon steel discs) | 1 per cap + spares | ~10 |
| 14 | 3M double-sided adhesive (e.g., 3M VHB tape or 3M 468MP) | Affix steel disc to cap | — | McMaster/Amazon | 1 roll | ~15 |
| 15 | M3–M6 bolt kit | Mount electromagnet holder to gantry head | — | [Amazon B0CLZC8SQ5](https://www.amazon.com/gp/product/B0CLZC8SQ5/) | 1 kit | 23.99 |
| 16 | PLA filament | Caps, mount, vial rack | — | any (Bambu, Prusament, etc.) | 1 kg | ~25 |

**Estimated module subtotal: ~$320** (items 3–5, 7, 9–10, 15–16 are shared/stocked shop
items — actual incremental cost is lower if the lab already stocks Arduinos, resistor
kits, jumper wires, bolts, and filament).

Notes:

- The paper specifies the exact electromagnet as "5V 50N, uxcell" and the sensor as
  "2168, Adafruit" (arXiv:2601.07043, §2, PAW module 2).
- Resistor values: the PANDA-BEAR BOM lists 10 kΩ + 200 Ω for the electromagnet circuit
  while the Construction Guide checklist lists 1 kΩ / 200 Ω / 3 kΩ for the full PAW —
  an assortment kit covers both readings; confirm against the
  [wiring diagram](https://github.com/BU-KABlab/PANDA-BEAR/blob/main/documentation/Arduino-Wiring.md)
  and [PANDA_Arduino firmware](https://github.com/BU-KABlab/PANDA_Arduino) pinout when wiring.
- If integrating with an existing gantry (CNC/Jubilee/Opentrons), the Arduino + shield
  can be replaced by any spare 5 V-tolerant GPIO + MOSFET driver you already have.

## 2. Parts to 3D print (in-house, PLA)

| File (committed in [`cad/`](cad/)) | Part | Qty |
|---|---|-----|
| `VialCap16mm.step` | Custom magnetic vial cap body | 1 per stock vial (print ≥10; validated across independently printed caps) |
| `PAW-V2-ElectromagnetMount.step` | Electromagnet + IR sensor mount for gantry head | 1 |
| `9VialHolder20mL_TightFit.step` | 9-position 20 mL vial rack (deck) | 1 |

Optional deck-mounting parts (PANDA-specific "pill" mounts) are in
[PANDA-BEAR/documentation/3D-prints/DeckAccessories](https://github.com/BU-KABlab/PANDA-BEAR/tree/main/documentation/3D-prints/DeckAccessories);
skip or adapt these if mounting the rack to a different deck.

## 3. Cap fabrication steps (per paper §3.1)

1. Print cap bodies in PLA.
2. Mix Sylgard 184 at 10:1 by weight, base : curing agent ("crosslinker"); fill the
   cap interior (~2.6 mL ≈ 2.7 g per cap); cure ≥48 h at room temperature.
3. Cut/punch steel discs to fit the recessed region on the cap top; attach with 3M adhesive.
4. Validate: run decap/recap cycles over a range of approach heights — expect ~3 mm
   vertical tolerance (paper Figure 2C).

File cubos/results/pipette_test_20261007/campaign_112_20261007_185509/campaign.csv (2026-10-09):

id | description | deck_config | board_config | gantry_config | protocol_config | created_at | status | finished_at | fluid_state_id
112 | Protocol run: gantry=/home/<user>/byu-vcl-pipette/cubos/configs/gantry/cub_xl_ben_3_instrument.yaml, deck=/home/<user>/byu-vcl-pipette/cubos/configs/deck/ben_2vials_tiprack.yaml, protocol=/home/<user>/byu-vcl-pipette/cubos/configs/protocol/vcl/pipette_test.yaml | /home/<user>/byu-vcl-pipette/cubos/configs/deck/ben_2vials_tiprack.yaml |  | /home/<user>/byu-vcl-pipette/cubos/configs/gantry/cub_xl_ben_3_instrument.yaml | /home/<user>/byu-vcl-pipette/cubos/configs/protocol/vcl/pipette_test.yaml | 2026-10-07T18:55:09Z | completed | 2026-10-07 18:57:25

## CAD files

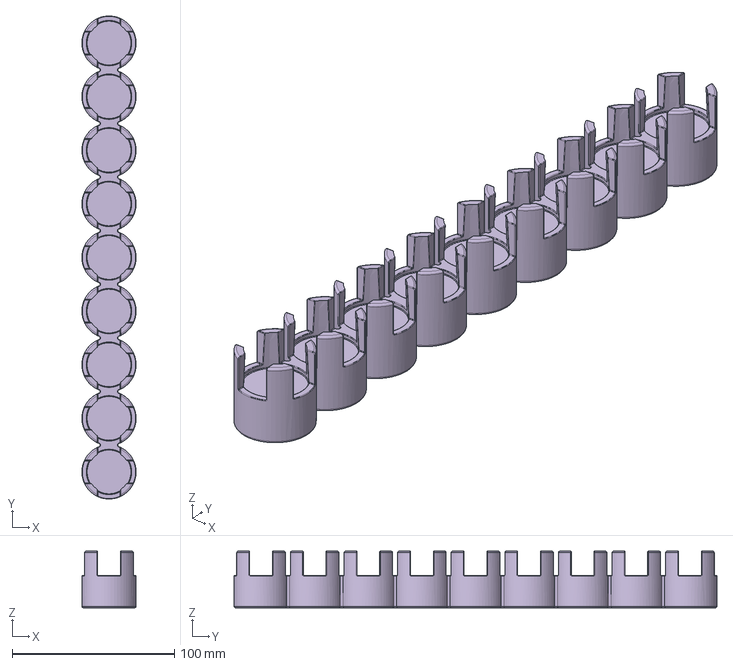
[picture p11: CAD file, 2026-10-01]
modules/electromagnetic-capper/cad/9VialHolder20mL_TightFit.step
33.4 x 297.3 x 35.0 mm

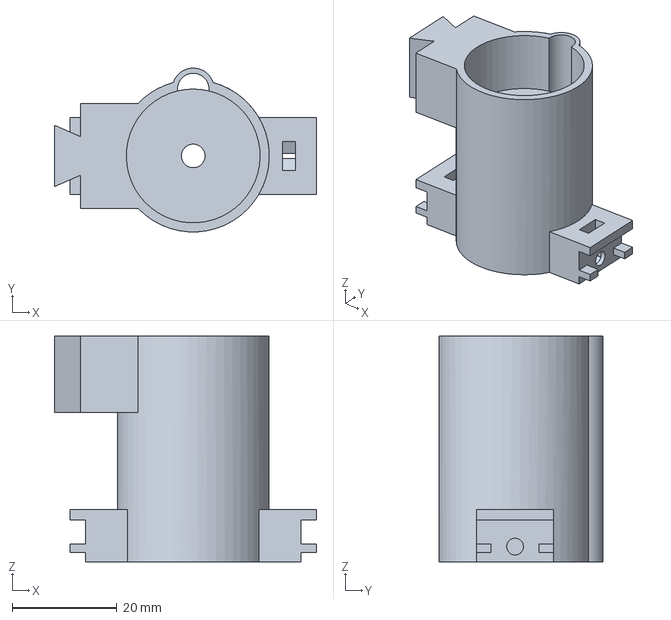
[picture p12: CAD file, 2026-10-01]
modules/electromagnetic-capper/cad/PAW-V2-ElectromagnetMount.step
49.9 x 31.2 x 43.0 mm

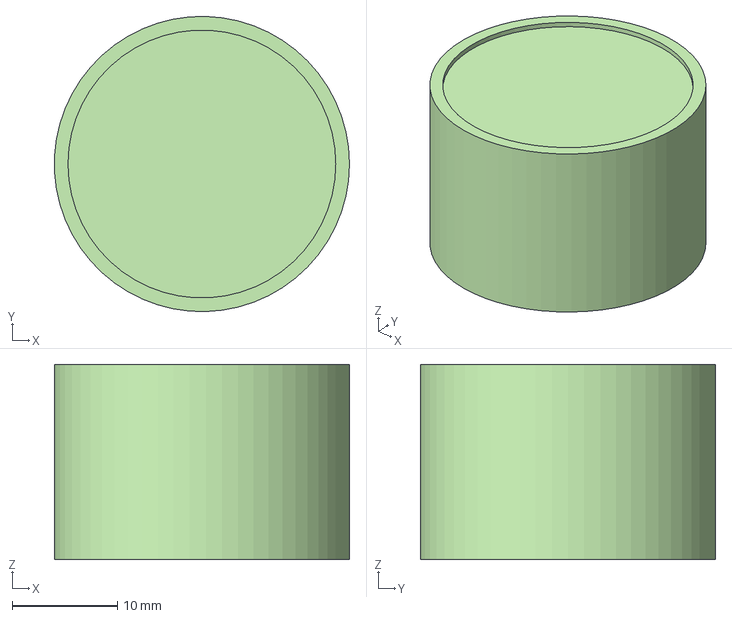
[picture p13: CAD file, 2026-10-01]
modules/electromagnetic-capper/cad/VialCap16mm.step
28.0 x 28.0 x 18.5 mm

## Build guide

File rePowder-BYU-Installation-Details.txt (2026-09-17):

# rePowder BYU Installation Details

  Meeting started: 9/17/2026, 8:00:06 AM
  Duration: 56 minutes
  Participants: Bartosz Kalicki, Dave, Gage Erickson, Sterling Baird

  [View original transcript](https://app.tactiq.io/api/2/u/m/r/cCdF7Qvts5v2gaqYv9ED?o=txt)

    ## Detailed summary with citation

# Meeting: rePowder BYU Installation Details  
Date: 2026-09-17  
Start time: 14:00:06Z  
Participants: Dave, Sterling Baird, Bartosz Kalicki, Gage Erickson

Below are topic-based summaries with one or more timestamp citations [mm:ss] pointing to when the topic was discussed in the transcript.

- Installation date and logistics
  - Bartosz confirmed traveling and preferring the 28th for installation; he may arrive earlier or adjust for other site visits. [00:20], [57:10]
  - Dave apologized for scheduling delays and noted campus constraints affecting timing. [01:00]
  - Bartosz expects the onsite work (setting machine in place, hookups, basic testing) to take ~2–3 hours if everything is ready. He plans to follow with training during his stay. [01:40], [41:30]

- Site readiness and room/enclosure
  - BYU has constructed an enclosure in the room; dehumidifier and ductwork/exhaust are installed to control environment for powder work. Recommendation: keep the enclosure slightly enclosed and use floor stickers at the entry to capture powder tracked out on shoes. [12:30], [13:50], [14:10]
  - Sterling proposed getting the dehumidifier running ahead of install to reach steady state. [59:30]

- Power / electrical connections
  - The atomizer and chiller come with 32A male plugs; options are either to provide a matching female receptacle or hardwire. Hardwiring is commonly recommended and sometimes required by local code. [03:30], [04:10], [05:10]
  - Bartosz advised he will measure voltage on-site before connecting (verify phases/voltage). Ensure access to 400 V and 230 V where needed. [22:00], [22:40]
  - Action: confirm correct plug/adapters or plan to hardwire. [04:40], [18:00]

- Cooling (chiller / heat exchanger / hoses)
  - The system uses a heat exchanger; there are different connector sizes (standard large connection vs. modified smaller 30 mm / ~3/4" or half-inch) and hoses supplied. The facility supply to the heat exchanger may require a one-inch connection/adapter to match facility coolant lines. [08:40], [10:10], [11:40]
  - Action: inspect supplied connectors on the wrapped heat exchanger, verify hose sizes, and obtain appropriate adapters/hose (BYU can supply or staff can go to hardware stores if needed). Bartosz offered to bring parts if missing. [09:00], [11:56], [15:10]

- Compressed air / gas connections
  - Compressed airline for the optimizer uses 6 mm (6/4 mm) tubing and push-fit connections; confirm regulator fittings and have push fittings/adapters available. [10:50], [16:00]
  - Argon: Bartosz recommended high-purity argon (5N, 99.999%) although 4.5N can be usable depending on material; system requires up to 8 bar (regulator capable of 0–10 bar recommended). Ensure regulator is adjustable to 8 bar and proper adapter from regulator to the 6 mm tubing is available. [16:20], [17:10], [17:50]
  - Action: Gage to confirm argon order purity with Nick and procure an appropriate regulator and adapters. [18:00], [59:00]

- Tools, consumables, and parts logistics
  - BYU (Dave) can assist as runner to obtain hoses, adapters, and fittings; Home Depot/Ace Hardware ok for small parts but some plug types cost more in certain regions. [06:20], [15:40]
  - Bartosz will bring some spare fittings (e.g., T-piece for gas lines) to cover minor missing items. [17:40]

- Installation sequence & training schedule
  - Installation: place machine, connect power/coolant/air, basic testing — 2–3 hours. Immediate theoretical briefing can follow; full hands-on training spans additional days (one day induction-specific + flexible second day), with Bartosz available and flexible on timing. [01:40], [43:10], [44:10]
  - Gage’s availability constraints were discussed (limited class windows on Monday); Bartosz will adapt schedule and can split activities across days. [45:40], [46:20]

- Machine details and internal capacities
  - Heat exchanger and optimizer connection design: a single connection area was modified to simplify hookup (one connection for the whole optimizer). The optimizer draw is ~60 A (so the plug is sufficient for both chiller and atomizer if wired appropriately). [08:10], [09:40]
  - Crucible and furnace dimensions: inner crucible height ~10–12 cm, usable diameter space ~20 mm between ceiling rod and crucible edge; material can slightly exceed crucible height but avoid overfilling. There is a ceiling rod; in some cases operation without ceiling rods is possible after discussion. [25:50], [26:20], [26:50]
  - Furnace operation: can start melting with the furnace open, but the locking bolt will not fully seal until closed; opening during operation is possible with modifications but not recommended for oxidation-prone materials (e.g., aluminum). [27:10], [28:00], [28:30]

- Recommended safety and powder handling
  - Anti-static apron and gloves are provided; Bartosz will supply an extra anti-static apron. Major risks require visible suspended powder for severe discharge events; standard PPE and conservative handling are recommended. [56:00], [56:40]
  - Powder storage recommendations: keep powders in sealed containers with desiccant packets (silica gel), vacuum bagging for shipping, or vacuum storage for more sensitive materials. Consider glovebox only for specific tasks; many customers operate without a glovebox if the handling area is kept clean. [58:00], [58:30], [59:40]

- Powder processing, alloying, and experiment planning
  - Bartosz supplied benchmark rods of Al 4047 for initial demonstrations; standard trial run duration ~1 hour. He suggested starting with aluminum as benchmark due to melting/flow behavior. [41:50], [43:50]
  - Powder in-crucible behavior: pure powder can appear not fully melted (individual particles persist). Better performance when some melted feedstock is present or when using pre-alloyed/master alloy. Use of master alloys or pre-melted feedstock is recommended for homogenous results. [31:50], [34:20], [35:20]
  - Mixing: induction causes some melt motion (pulsation) that provides mixing, but not a substitute for master alloy/additions. For high-melting additives or difficult-to-dissolve materials, pre-alloying (e.g., arc melter) is preferred. [33:10], [34:40]
  - Proposed experiments: (1) atomize high-purity solid Al rod feedstock, (2) test a bored-out Al rod packed with powder (press-fit cap) to attempt full melt/atomization. If packed powder fails to fully melt, options include pre-alloying via arc melting or other consolidation (vacuum press, hot pressing) before atomization. [52:20], [53:50], [54:20]

- Materials and procurement actions
  - Sterling/Gage plan to order two sizes of high-purity Al rods (20 mm O.D. and a smaller diameter for press-fit cap); suggest McMaster or alternate suppliers to get highest purity available. Gage to research and order via BYU procurement (McMaster credentials). [60:10], [61:00], [62:00]
  - Consider procuring master alloy by arc melting powders (Taylor Sparks / University of Utah arc melter discussed). Action: Gage to contact Taylor Sparks (cc Sterling) to ask about feasibility/scheduling and possible student assistance for arc melting before the install so a prepped sample can be atomized while Bartosz is onsite. [68:00], [69:20], [71:00]
  - Consider buying commercial powders (Valent or similar) to compare commercial ALS I10MG powder to in-house-prepared alloys. Discussed possible road trip/visit to local industry (Valmet/Valent) for powder handling and safety best practices; lab funds would cover travel. [77:10], [78:10], [80:00]

- Action items and assignments (explicit)
  - Gage: walk the site with phone to show electrical, chiller, transformer location; confirm hoses/adapters and argon purity/regulator; coordinate with Nick for argon/regulator and with Kevin for push fittings. [06:40], [17:50], [18:40]
  - Dave/BYU: act as runner for parts and supplies, confirm available hoses and adapters on campus. [15:30], [16:00]
  - Bartosz: will bring spare fittings (e.g., T-piece), supply training videos and access to the online database, conduct installation and training, measure plug voltage on arrival. [11:56], [41:30], [22:00]
  - Sterling: arrange dehumidifier startup, order/approve purchase of high-purity Al rods, procure extra desiccant, and review glovebox/enclosure options (budget up to ~$4–5k discussed). [59:30], [60:50], [63:40]
  - Gage: research/purchase McMaster Al rods and desiccants, email Taylor Sparks re: arc melting (cc Sterling), and coordinate with Barry/Kevin/Nick for hoses, fittings, and gas. [61:00], [69:20], [18:40]

- Training resources and documentation
  - Bartosz will add BYU staff to his database/website with operation videos and documentation covering assembly, operation, and part lists. Those resources should be reviewed in advance of hands-on training. [73:00], [74:10]
  - Sterling/Gage plan to capture installation videos for internal use and to watch supplier training videos if needed. [74:50]

- Scheduling constraints & next steps
  - Bartosz prefers 28th arrival and will adapt schedule; installation on 28th with subsequent training over next two days is preferred but flexible depending on travel/other visits. [00:20], [57:10]
  - Gage notified class constraints (limited windows on Monday); all agreed to coordinate precise start times (morning vs. afternoon) and split training across days as needed. [45:40], [46:20]
  - Next immediate tasks: confirm argon order/purity and regulator; verify onsite power plug or plan hardwire; inspect heat exchanger connectors and identify required hose/adapters; start dehumidifier; order high-purity Al rods; contact University of Utah (Taylor Sparks) about arc-melt assistance. [16:20], [22:00], [11:40], [59:30], [61:00], [69:20]

If you want, I can extract the exact transcript timestamps in mm:ss for each quoted snippet or produce a compact checklist of open items with owners and due dates for follow-up.

    ## Highlights

    > 12:49 Gage Erickson: OK OK, perfect. I I talked to Nick about getting argon. So that should be coming in tomorrow or the next day.
> 13:44 Bartosz Kalicki: But if you were to want to process copper, then it's not going to be such an issue for you.
> 14:25 Bartosz Kalicki: You know, as long as it gives us the 400 volts and 230 volts, we are fine. What is important is definitely that when I will get on site I will first measure the voltage in the plug before we get everything connected, just in case, just to make sure nothing was swapped because you know we use different a bit different colors.
> 30:30 Bartosz Kalicki: I mean we are using like gloves. We have the anti static aprons. But in order to have the real issue, you would need to have the powder suspended in the air.
> 40:24 Sterling Baird: Yeah. Yeah, so. We. If it becomes a big issue with the powders not I mean like.
> 54:13 Gage Erickson: I'll talk to Nick about making sure we get five in argon. I'll work with Dave for I'll work with Dave for the pipe hookups and all that. If you'll send me the important part of the transcript for that.
> 54:53 Gage Erickson: Good. That's an important skill, especially in running a business.

  ## Transcript

  00:00 Dave: Hi, sterling.
00:02 Sterling Baird: Hey, how's it going?
00:04 Dave: Good morning Good morning.
00:06 Bartosz Kalicki: Hi.
00:07 Sterling Baird: Winning and hey, bartaj. It's good It's good to put It's good to put a face to the to the name. Thanks for all your help so far bartaj on getting this getting all this going. It's been really helpful.
00:21 Bartosz Kalicki: No problem. Yeah. Also, at this point, it seems that I can confirm that we will go with the 28th.
00:29 Sterling Baird: OK.
00:30 Bartosz Kalicki: I'm checking if I will have to squeeze a visit to New York on Thursday, Friday, depending on how they will be able to and so on.
00:36 Sterling Baird: OK.
00:42 Bartosz Kalicki: But 2028, there definitely would be too soon, so I will go first to.
00:45 Sterling Baird: OK.
00:47 Bartosz Kalicki: Salt Lake City, then.
00:49 Sterling Baird: OK, great.
00:55 Bartosz Kalicki: Is everything? Mm-hmm.
00:57 Dave: Is, is, is Gage joining us, sterling.
00:59 Sterling Baird: I I just messaged him. It looks like, oh, he's typing back to me, so just a second.
01:06 Dave: OK.
01:14 Sterling Baird: Based on that, I'm guessing the answer is yes, yes. Yeah, he's turning. And then thanks to Dave and Gage and and many others, all renovations are are done. It sounds like in terms of like just everything that needs to happen for. The The atomizer, if I'm correct there, Dave. I'll put you there.
01:47 Dave: Yeah, I I'm I apologize for the length of time this has taken Bartos. I know we were hoping to. Get it done very quickly, but we're kind of at the mercy of the. People here on campus, and we can only push so hard.
02:04 Bartosz Kalicki: Mm-hmm.
02:07 Dave: So sorry about the delay.
02:08 Sterling Baird: While
02:08 Bartosz Kalicki: I fully understand we had one more system that was shipped around the same time, but right now it seems that the installation will be more like in December because because of how much work is actually needed and how they need to do stuff that they do not really.
02:08 Sterling Baird: While still remaining friends. OK. Gotcha.
02:26 Bartosz Kalicki: Want to do and it just keeps being pushed further all the time. So So.
02:33 Sterling Baird: I'm sorry.
02:33 Bartosz Kalicki: It it It it all happens It it all happens. Or waiting times, especially electrical work is always. A
02:39 Sterling Baird: Mm-hmm.
02:39 Bartosz Kalicki: A nightmare. That's why we usually to have for the transformer that we normally use because they allow it to be delivered within a week. They always have everything in stock. It's a. They have also a good quality to money. Perspective. So it helps a lot, but in general still it always takes a long long time. Perspective so
02:56 Sterling Baird: Mm-hmm.
03:03 Bartosz Kalicki: So right now, because so in this case I understand we have for the power for the optimizer. So for the induction model here we have the power for the chiller. The question is do you? Do you want to hardwire it or do you have any plugs already? Do you know what's the plan on that?
03:22 Dave: I think right now the main power for the machine actually has a plug. And we can make sure that we have the correct plug. The The the The the male plug to hook to the machine or when if we decide we we could also hardwire it.
03:39 Bartosz Kalicki: Mm-hmm. OK.
03:44 Dave: So.
03:45 Bartosz Kalicki: I'm in both that. Yeah, both the chiller and the atomizer. They come with the 32 amper male plaque already. So in this case you can either go for the female plag as a direct connection or something to put on the wall, but to be honest, hardwiring it is probably the most common. It saves money because the plaques, especially if you know in here I get the plaque for.
04:11 Bartosz Kalicki: 30 $30. $40 in states I did sell them for hundreds just because of some additional certification and so on.
04:14 Gage Erickson: 3rd.
04:21 Bartosz Kalicki: So So most people
04:21 Dave: Yeah.
04:21 Bartosz Kalicki: So most people actually just hardwire. See directly and in some states like New York, it's even the low that if the system is going to be permanently there, it has to be hardwired.
04:29 Dave: Yeah.
04:32 Bartosz Kalicki: So this is actually something I would recommend to do.
04:37 Dave: Gage, since you're since you are down there, you could go and point your camera at the electrical that we have set up for it and also show the chiller. Drop Drop drops are Drop drops are in place and show what we have and then I think that might be a good idea. And then Bartos can comment on what he thinks we should do.
05:02 Gage Erickson: Sure. Let me. Let me join from my my phone and then I'll walk over there.
05:06 Dave: OK, OK.
05:07 Bartosz Kalicki: Yeah, yeah.
05:08 Gage Erickson: Let's see.
05:10 Sterling Baird: W.
05:10 Bartosz Kalicki: So in terms of power, the only thing is, depending on the regulation at your place, if we will see that we will need to swap the phases.
05:19 Gage Erickson: If we will see, sorry.
05:26 Dave: OK. So Gage, let's just kind of show the outside of when you get on your phone, just kind of pan and show them what we're doing. Let's just give him an overall mental picture here of of what he will be doing.
05:43 Gage Erickson: Yeah, so here's our. Yeah, so here's our. Just gotta switch off. Just got to switch over.
05:49 Dave: Yeah. Turn off your. You need to turn off your computer one. That's all we're seeing right now.
05:54 Gage Erickson: Computer.
05:57 Dave: Yeah. Now, now we have no audio or visual from you.
06:13 Sterling Baird: Oh, I see, I'm seeing.
06:13 Bartosz Kalicki: I I mean, I see. I see from the phone so I have. Yeah.
06:16 Dave: OK. I I am not, but that's fine as long as you guys are.
06:20 Bartosz Kalicki: Yeah, I see the view from the phone. So OK and we lost.
06:29 Dave: So just Bartos to bring it up to speed in the space where we have, we actually constructed an enclosure within the room. There we go.
06:40 Gage Erickson: Can you hear me now?
06:40 Dave: There we go. Yeah, that's great.
06:42 Gage Erickson: OK.
06:43 Sterling Baird: Yep.
06:43 Bartosz Kalicki: Yes.
06:44 Gage Erickson: Alright
06:44 Dave: So we've got this enclosure, go for it.
06:44 Gage Erickson: Alright so here.
06:46 Bartosz Kalicki: I see. OK. That's perfect.
06:55 Gage Erickson: So here's the atomizer kind of draped in. The wrapping still. So here's here's the yeah go ahead, Dave.
07:04 Dave: And. No, you explain as you go.
07:07 Gage Erickson: OK. So here's the the chilled water and return type's there, and this is a compressed air. And then here's our electrical down at the bottom here.
07:19 Bartosz Kalicki: OK, so you have for that plug directly on the wall, OK. Perfect. Yeah. OK, now I sorry. Now I remember that we did the modification for you to make it all easier. So you have the heat exchanger, you have the additional plug on the back for it so that we have one connection for the whole optimizer.
07:35 Sterling Baird: Good.
07:41 Bartosz Kalicki: In general, it's fine because the optimizer takes up to, I think 60 number by itself. So the plug So the plug is enough easily enough for both. OK then. Yeah, we will use that chilled water. So in this case, it's always about the small details. For example, what kind of holes right now can we connect to the chilled water? Because with the with the heat exchanger in, let's say the standard is a pretty large connection.
08:03 Sterling Baird: Mm-hmm.
08:09 Gage Erickson: I.
08:11 Bartosz Kalicki: But I think it was changed to the smaller one, so the 30mm. Hose.
08:18 Dave: Not something Gage that's something Not something Gage. That's something we need to look at and make sure that we have these are going to be SAE standards and so. I think I think those are probably three quarter threads, so we'll we'll make sure that we have appropriate adapters to hook the chilled water to the heat exchanger.
08:40 Gage Erickson: This is on the the heat exchanger.
08:42 Bartosz Kalicki: I I mean he no, I mean heat exchanger should already have the connectors.
08:45 Dave: OK.
08:46 Bartosz Kalicki: So you can easily unwrap it just to take a look on the on the outlets that are currently there. If something will be missing, I can just take it with me.
08:49 Dave: OK.
08:51 Sterling Baird: Hmm.
08:56 Bartosz Kalicki: But it should have both options. An option for a large 25 millimeter hose as we are using normally and the smaller one for 30mm. So in this case it's probably set for 30mm.
09:09 Dave: OK
09:09 Bartosz Kalicki: If not, we will just have to do the swap, but that can be on me, so the best will be probably to use 1/2 inch hoses to for everything. We will use the 30mm connections, it will fit well.
09:10 Dave: OK. OK.
09:23 Bartosz Kalicki: And it should be fine on both ends.
09:24 Dave: OK.
09:24 Bartosz Kalicki: And it should be fine on both ends
09:30 Dave: He's gonna. Yeah, take that apart. We Gage. We probably need to make sure that we've got some hoses.
09:38 Gage Erickson: Thank you.
09:38 Dave: So. We'll need to have a chat with Barry to make sure we have the hoses.
09:47 Bartosz Kalicki: Yeah Yeah you can check how much Yeah, you can check how much was supplied with the atomizer itself, because there should be already a bit of the extra hose in there. You know, in the worst case scenario anything will be needed like small parts which may be a nightmare sometimes on your end I will.
09:52 Gage Erickson: Hello.
09:52 Dave: Yeah.
09:52 Gage Erickson: Go ahead.
09:55 Dave: OK.
10:04 Bartosz Kalicki: Drive to Ace Hardware or Home Depot, then get it.
10:07 Dave: We OK, we we can help with that as well and we have pretty good supply. Things Things here at BYU, so that shouldn't be a problem. My my plan. For my purposes, being there will be to kind of be a runner for you to make sure we can get all the things that we need for hookups as as far as hoses go, is there AI mean, do we need to do high quality industrial hose it doesn?
10:31 Bartosz Kalicki: Of course.
10:38 Dave: Feel like we should put. Garden hose Garden hose on there for example, but.
10:43 Bartosz Kalicki: No No, definitely not a garden hose, OK? So I see what it is right now about. So we have them. So we will need to hook up the facility to the main coolant in and out. So this is in a one inch, so we will probably need to put an adapter on your side to go from what size you have.
11:02 Dave: OK.
11:02 Bartosz Kalicki: To the one inch and put a one inch holes in between OK.
11:05 Dave: Oh. OK.
11:08 Bartosz Kalicki: Yeah, there is nothing right now. So we will need to connect the one inch and you can see that on my side already. It was fitted to half inch. So the same size as is in the induction module and there should be that holes included with the system.
11:12 Dave: OK.
11:24 Bartosz Kalicki: Right now, the fitting that was kind of like empty. In another package, yeah. Exactly.
11:32 Dave: Also that that hoses intended for the for the coolant loop.
11:34 Bartosz Kalicki: On my. Yeah, I mean, so this is the smaller one. So this is the half inch. This one will be between the exchanger and the optimizer.
11:45 Dave: OK.
11:46 Bartosz Kalicki: So as a supply and return. So it seems only what we need is a bit of one inch holes to connect between the heat exchanger and the facility.
11:48 Dave: OK. OK. We we will. We will make sure that we have stuff for that.
12:05 Bartosz Kalicki: OK, so coolant is fine.
12:06 Dave: And then the compress compressed airline, same thing we can, it's right there on the wall next to the heat exchanger lines, so.
12:16 Bartosz Kalicki: OK. Yeah, same thing. Just to make sure that we can connect the 6mm line directly to the back of the optimizer so you can see that the six per 4mm tubing is already included.
12:25 Dave: OK.
12:31 Bartosz Kalicki: It's just to make sure that you have the right connector, otherwise it will be a nightmare to get. And yeah, I even know that you can get those on Amazon if needed.
12:42 Dave: Gage, I think we need to chat with Kevin. I think Kevin's got all the push fittings that we need to hook up to the compressed air there.
12:49 Gage Erickson: OK OK, perfect. I I talked to Nick about getting argon. So that should be coming in tomorrow or the next day.
12:56 Dave: OK. OK.
12:59 Gage Erickson: Although Bartos the we we had an option between like 100% argon and research grade argon. Do you know if? If it matters so much, as long I mean, as long as there's not octane. Right, it's fine.
13:12 Bartosz Kalicki: We yeah, we are using usually the five N so 99.999.
13:18 Gage Erickson: Uh.
13:18 Bartosz Kalicki: But it all will depends at the end about the material that you are using, because it's just that with even with many pages we will just be able to reach certain level of oxygen. That will depend on the purity of the argan that you have. But even if. It will be like 4.5 N it still will be usable. It depends on the material. For aluminium magnesium we definitely want to go with as little oxygen as possible.
13:42 Gage Erickson: Good evening.
13:44 Bartosz Kalicki: But if you were to want to process copper, then it's not going to be such an issue for you.
13:49 Gage Erickson: OK.
13:50 Sterling Baird: Yeah. So probably we do five and then just given the aluminum.
13:55 Gage Erickson: Then I'll I'll check with. Nick again about Nick again about the purity level of the argon we order.
14:02 Dave: OK. Gage while you're there
14:04 Bartosz Kalicki: Yeah. So.
14:05 Dave: Gage. While you're there, let's flip your phone again. Gage while you're there let's FL Let's show Bartos, the transformer and maybe step up the ladder there. Show him what's up on top. So there there's our transformer location.
14:17 Bartosz Kalicki: Mm-hmm.
14:22 Dave: Next to the room and then.
14:25 Bartosz Kalicki: You know, as long as it gives us the 400 volts and 230 volts, we are fine. What is important is definitely that when I will get on site I will first measure the voltage in the plug before we get everything connected, just in case, just to make sure nothing was swapped because you know we use different a bit different colors.
14:40 Dave: OK, OK. OK.
14:47 Bartosz Kalicki: Yeah, that should be fine.
14:50 Dave: And then yeah, this is up on top. So we've got the dehumidifier. And all of the ductwork and and this isn't specific for you, but this is so that we can do proper exhaust in that room for everything we're doing inside.
15:07 Bartosz Kalicki: I mean in case of work with powder, that's definitely something that is recommended if possible, is recommended to have it slightly enclosed. The powder will always have the tendency to just move around. If If you want, my only recommendation would be that if you know where it's going to be a puff out from the enclosure, you can put this kind of like stickers on the floor that when they get dirty you just remove one. You have one underneath, and anybody that's leaving the room has some powder on like the shoes is going to leave the. It's on the sticker.
15:39 Sterling Baird: OK.
15:40 Gage Erickson: Good idea.
15:41 Dave: Oh, I like that.
15:42 Bartosz Kalicki: So if
15:42 Dave: OK.
15:42 Bartosz Kalicki: So if you have such a good enclosure, that's that's the last recommendation I would do there. Yeah. In case of argon, my only thing is that it has to be 8 bars.
15:47 Sterling Baird: OK. Thanks.
15:54 Bartosz Kalicki: So what? You need to make sure that when you have the regulator is the one that allows you to change the pressure. For example, in the range of zero to 10 bars. But for example, if you have a already in regulator, but it's a welding regulator, they are usually set.
15:54 Sterling Baird: Hmm.
16:07 Bartosz Kalicki: To free bars and you can only set the flow. But this system has quite But this system has quite a lot of. Nomadic systems inside which allow the higher pressure to be available.
16:18 Dave: OK.
16:20 Sterling Baird: That's 116 P, SII think.
16:20 Dave: Gauge that. Gage, do we already have the regulator for the argon?
16:25 Bartosz Kalicki: Steve.
16:31 Gage Erickson: No I don't think No I don't think so No, I don't think so.
16:33 Sterling Baird: Yeah, this doesn't sound familiar.
16:33 Dave: OK.
16:34 Sterling Baird: Yeah this doesn't sound familiar
16:34 Dave: That's a. That's a, that's a question to ask Nick when you ask him about the argon. Let's make sure that we've got a proper regulator by the time he Bartos gets here.
16:47 Gage Erickson: A. An 8 bar regulator.
16:50 Dave: Usually like. Like Barto says we we can get an adjustable 1. Nick will be our best source of knowledge there of where? But yeah, like like he says, minimum of eight bar.
16:57 Sterling Baird: Mm.
16:59 Gage Erickson: Show me.
17:00 Sterling Baird: Yeah. Mm-hmm.
17:04 Gage Erickson: OK.
17:05 Bartosz Kalicki: Yep, it's usually going to be zero to 10. I guess when you have this kind of range, but we just need to make sure that we can set 8.
17:09 Dave: Yeah.
17:10 Gage Erickson: OK. Sounds good.
17:15 Bartosz Kalicki: OK. Yeah. So in case of so that would cover argon.
17:22 Gage Erickson: OK.
17:22 Bartosz Kalicki: Same thing is just to make sure that we have the right connection, the right tube getting us from the tonic to the system. So prob So probably you will also need to find the right adapter to put on the regulator there.
17:36 Gage Erickson: Is that go directly into the atomizer?
17:40 Bartosz Kalicki: I I it should if you can take a look on the back, it should have.
17:43 Gage Erickson: Yes.
17:46 Bartosz Kalicki: There should be AT for that. I need to see what was the last OK. Yeah, you can see the 22646 per 4mm connections. This is where we are going to connect argon and with the parts there should be AT used for it.
18:06 Dave: OK.
18:10 Bartosz Kalicki: Yeah Yeah, but one. There was just like one is pressurizing the furnace itself. The other one goes to a valve that allows us to feel the Chamber.
18:20 Dave: OK
18:20 Bartosz Kalicki: But both are 6 per four and I will just make a comment to make sure that maybe I will bring an extra tea.
18:21 Dave: OK.
18:27 Bartosz Kalicki: We'll meet just in case.
18:28 Dave: OK. And then and then Gage will work to make sure that we have all the correct adapters to get from the argon tank to the 6mm. It's the plastic tube.
18:41 Gage Erickson: Sounds good.
18:42 Dave: So OK.
18:46 Bartosz Kalicki: All right, so we have enough space. Everything is planned, the installation if everything will be kind of like a plaque play. The installation will take two hours, maybe three hours top just to set it in a position connected to some basic testing, and then we will be able to just start the operation. So we. Will go through some theoretical training. I will add you then to our database system where you will be have access to some videos on the operation of the system and with the system we have supplied roads of aluminium 4047 which is kind of like a benchmark material which we use for the.
19:28 Sterling Baird: Hmm.
19:29 Bartosz Kalicki: Showcase of the machine. It's if we don't want to like for example in case of copper you need to wait longer for cooling it for heating up in case of. Teen and low melting Teen and low Mel Teen and low melting point. It's just going too quickly. So we usually use aluminium. And I added some extra rods so that we can make more trials. One trail is usually taking one hour, but if you will have something in mind that you would like to maybe test it together, we can plan time for it.
19:52 Sterling Baird: OK OK. OK. Yeah, actually, yeah, that would engage. We should probably chat about what we might want to try out and maybe get a get a sample ready.
20:10 Gage Erickson: Yeah.
20:12 Bartosz Kalicki: Yeah, you can see if if you open the furnace part you will see exactly the area where we can fit the material.
20:14 Gage Erickson: Yep.
20:21 Bartosz Kalicki: So in case of like maximum diameter is 20mm on the on the right you have the lock. Yeah. And if you just move the foam out, you can see the Crucible. So we have a Crucible. Inside is a ceiling rod and you can fit the material in this space in between.
20:40 Gage Erickson: OK. OK. Hmm.
20:45 Bartosz Kalicki: So it should be around 20mm between the ceiling rod and. The The edge The edge of the Crucible. In some cases it is possible to work without the ceiling rods if it will have. If it will be necessary, but we will have to discuss it and but once you get a little bit of knowledge, it is possible to operate that way too. So if you have a feedstock that is really hard to put otherwise like some chunks, you need to just drop it.
21:13 Sterling Baird: Hmm. What? What's the height that we could? I'm I know the Crucible dimensions.
21:21 Bartosz Kalicki: 1212 centimeters, I would say.
21:24 Sterling Baird: OK.
21:24 Bartosz Kalicki: The mater The material can slightly even
21:26 Gage Erickson: And.
21:26 Bartosz Kalicki: The material can slightly even be higher than the Crucible. I would say the inner height is around 1011 centimeters, but we can go a bit higher than that.
21:32 Sterling Baird: OK. Yeah. OK.
21:36 Bartosz Kalicki: You just need to make sure that it will not over fill the Crucible once everything melts.
21:41 Gage Erickson: Do you?
21:41 Sterling Baird: OK.
21:43 Gage Erickson: Do you? Do you only turn on the heat once? This is closed. Or can you start melting it with it open?
21:51 Bartosz Kalicki: You can. You can start melting it with it open, but I would say there is no reason to unless it is a very specific kind of research that you want to perform once you close the fairness and you change the pressure in the furnace, it automatically locks there is like.
22:04 Gage Erickson: Catcher.
22:11 Bartosz Kalicki: A A bolt coming and locking the furnace. But if you start with it fully open. The bolt will get in, but it will not be able to block anything. The bolt will get in but it will not be able to block any
22:19 Gage Erickson: Yeah. Gotcha. OK.
22:25 Bartosz Kalicki: But it is possible there are like also some additions of like different flavors or some additions to the flap that allow to open the furnace in the middle of operation just a little bit to like place some more material inside.
22:25 Gage Erickson: And.
22:39 Bartosz Kalicki: It is fine, but it's fine. More like for gold. Silver maybe copper materials that do not oxidize so easily. Otherwise I would try to avoid it. In case of aluminium it can affect the flow.
22:54 Gage Erickson: Gotcha. Makes sense.
22:55 Dave: OK. OK. Looking forward to seeing you Bartos. Looking forward to seeing
23:04 Sterling Baird: I.
23:05 Dave: I need to go to another meeting, so I'm gonna let you guys go and I will be there on the 28th to help wherever I can.
23:07 Sterling Baird: OK.
23:08 Bartosz Kalicki: No problem.
23:15 Dave: Make sure we facilitate a smooth transition here, so we will see you on the 28th Bartos. Thank you.
23:23 Sterling Baird: Could you stay on for a second bartosh?
23:23 Bartosz Kalicki: Yeah. Thank you a lot.
23:24 Gage Erickson: OK.
23:26 Sterling Baird: Thank you, Dave. Yeah, appreciate it.
23:27 Bartosz Kalicki: Yeah, of course.
23:28 Gage Erickson: Thanks, Liv.
23:31 Sterling Baird: Awesome Awesome and Awesome. And then pronunciation of your name is A is a. How do you pronounce your name? Just so I don't.
23:38 Gage Erickson: But.
23:38 Bartosz Kalicki: Bartos.
23:40 Sterling Baird: Bart Bart those OK Bart, those OK, cool. The The there were two other things just kind of a quick note to gauge. It might be worth getting trying to get the dehumidifier running in advance of. Well actually I think it would be really good to try to get the dehumidifier going. Before. Installation and have it like just kinda see what our steady state is gonna be.
24:05 Gage Erickson: Mm-hmm.
24:05 Sterling Baird: For things For things and then also get the I think I'll order another error gradient like monitor that we install inside the enclosure and then and then bhartaj one of the things that we've been kind of. For things and then also get the One of the things we've been kind of behind on is. Glovebox handling of of the powders.
24:27 Bartosz Kalicki: No worries.
24:30 Sterling Baird: In your. In your experience, and I guess what you see at different different places, like if we went with one of the. Cheaper plexiglass style glove boxes that still has a antechamber or like bringing things in and out. Does that seem sufficient? I'm I'm usually work used to working in a battery glove box.
24:48 Bartosz Kalicki: I would say it is.
24:50 Sterling Baird: Yeah, go ahead.
24:51 Bartosz Kalicki: I would say it is I would say it is. It all depends what you actually are going to work with, but to be honest, most of the customers, most people that we work with, they do not operate with the globe box. If you have an area that can be kept clean and where you can handle the pow.
25:03 Sterling Baird: OK OK. OK.
25:10 Bartosz Kalicki: That's going to be generally enough That's going to be generally enough if you definitely don't store it in like a, you know, just a plastic box.
25:12 Sterling Baird: OK.
25:19 Bartosz Kalicki: Have some containers and it's just good to put some silica gel pockets in the container for storage of the powder. That helps a lot.
25:20 Gage Erickson: And.
25:22 Sterling Baird: OK. OK.
25:28 Bartosz Kalicki: Otherwise, it may clump a lot or even oxidize over time.
25:29 Sterling Baird: Yeah. Gotcha. Yeah.
25:33 Gage Erickson: It's like the.
25:34 Sterling Baird: OK. Yeah. So to put those in the in the container itself, yeah.
25:36 Gage Erickson: Oh, is it called death certificate? Like this can happen.
25:40 Bartosz Kalicki: Yeah, but glove box sometimes we operated. But, but only when we like pack a samples that we are shipping. But very often when we pack the sample, we just then put it into a, let's say, a vacuum bag that we, you know, vacuum and keep that way even if even if there is a little.
25:52 Sterling Baird: Goodnight. Yeah. OK.
26:03 Bartosz Kalicki: Bit of air. If the powder is already like, well passivated, it will not be a problem at all.
26:06 Sterling Baird: Yeah. OK. That makes a lot of sense.
26:13 Gage Erickson: So you should.
26:14 Sterling Baird: Oh, so yeah, go ahead, Gage. OK.
26:17 Gage Erickson: Bartow, she said that on the 20 on the 28th, you'll do the installation. That'll take like two or three hours, and then how how? How many hours of training is there after that?
26:24 Bartosz Kalicki: Yeah. Let's see. I mean, two more so we can still work that first day already on the theoretical side and general work and then for the two more days full hours, I'm just going to be with you and we will handle the training. So more or less when I will final. My part we can just do whatever you would like to work with.
26:53 Gage Erickson: OK
26:54 Bartosz Kalicki: And usually the training is one day for the induction year, so one day will be probably more around the necessary parts and one day can be more flexible.
26:54 Gage Erickson: OK. Awesome. Do you? Do you know? Do you have any kind of like a hourly schedule yet for the 28th? What? What time you plan on being here?
27:17 Bartosz Kalicki: I I do not have my flight yet as I'm just trying to, let's say, organize everything, but I will probably arrive a little bit earlier just to maybe be on Saturday just to have a little bit of rest and then we can just start early. Whatever time is comfort. For you, we can start and same in case of what time we will finish, I will finish on that time.
27:42 Bartosz Kalicki: No no problems No, no problems.
27:45 Sterling Baird: Yeah.
27:45 Gage Erickson: Yeah, the I've got. I've got. Classes Classes at my university for majority of of the day on Monday. Classes at my university So like there'd be there'd be like maybe two or three hours that I could be there, but intimately throughout the day, you know? So I won't be.
27:54 Bartosz Kalicki: Mm-hmm.
28:02 Gage Erickson: I won't I I won't. I won't be like available for majority of that day, so.
28:07 Bartosz Kalicki: It's OK. I mean, most of the work will be done in the two next days if you know the schedule, we can kind of just like plan the day. That way I can, you know, I can just we can do the installation then we can make a longer.
28:12 Gage Erickson: OK.
28:22 Bartosz Kalicki: Break and we can even meet in the afternoon. In my case, I'm really flexible on that. In my case I
28:29 Gage Erickson: OK.
28:30 Bartosz Kalicki: So whatever schedule is going to be comfortable on those three days, I will keep to that.
28:37 Gage Erickson: Yeah. I mean, at least, at least for me, sterling, I don't know what your schedule is like that day, but probably from 1:00 to 4:00 is? I I I I could I I could on Monday I could use I I could on Monday I could use that time. Here at the atomizer but Here at the atomizer but outside of one to four I
28:52 Sterling Baird: Oh, OK.
28:52 Gage Erickson: Here at the atomizer, but outside of one to four, I'd be kinda busy so.
28:54 Sterling Baird: Yeah, I mean, I teach. I teach at noon Monday, Wednesday, Friday. That's my only part constraint on things so.
29:01 Gage Erickson: OK.
29:03 Sterling Baird: Yeah, so I think. I think we should be OK in terms of. Scheduling Scheduling in time
29:08 Bartosz Kalicki: As I said, if if you will want if we'll see that OK, we need to wait like working to be longer, it's fine.
29:08 Sterling Baird: Scheduling in time 10%. OK.
29:18 Bartosz Kalicki: It's for me. It's perfectly fine. We can start as early as you want and then the idea is just to make sure that we finish everything during the my stay with you.
29:29 Gage Erickson: Mm-hmm.
29:31 Bartosz Kalicki: So that's all.
29:31 Sterling Baird: Yeah. Yeah, one. And I guess a couple couple more things that come to mind. One is that we did a test of our vacuum. It seems like we're OK on the like our explosion proof vacuum side things. So we've got we've got that. Anti this was kind of another maybe another question of based on what you've seen like. Anti Anti static. Like.
30:03 Bartosz Kalicki: So what? What you get with this system?
30:05 Sterling Baird: Shoes and Shoes and other things yeah go Yeah. Good.
30:08 Bartosz Kalicki: What you get with the system is an anti static apron.
30:13 Sterling Baird: Yeah.
30:13 Bartosz Kalicki: You're. I'm also having one more of those for you.
30:15 Sterling Baird: OK. Thank you. Yeah.
30:16 Bartosz Kalicki: You just put, you know, the strap you put it on the hand. So in general this is kind of like a it's advice to use, especially when handling large amount of powder. But to be honest we are not really doing that.
30:20 Sterling Baird: Yeah. Yeah. OK.
30:30 Bartosz Kalicki: I mean we are using like gloves. We have the anti static aprons. But in order to have the real issue, you would need to have the powder suspended in the air.
30:39 Bartosz Kalicki: You will have to have a like a real visible discharge, so it's not something that can happen so easily.
30:46 Sterling Baird: OK. So precaution. Yeah, like precaution.
30:49 Bartosz Kalicki: Yeah, definitely. Let's make sure that we don't handle the powder well, but that's it.
30:50 Sterling Baird: And then wait a minute. Yeah, yeah, that makes sense. Alright. And then for one of the samples that we want to test, actually we probably wanna run two tests. One is that we'd have some high purity aluminum rod that we would try atomizing and then another sample that's a high purity aluminum rod that kinda has a is bored out. So it's sort of like a intercruciable that we. Pack powder into.
31:23 Sterling Baird: Like other other types of powders to get Like other other types of powders to get our. Are other elements in there and then the thought was that we would kind of cap it or or use like a press fit?
31:27 Bartosz Kalicki: Mm-hmm.
31:34 Sterling Baird: And like And like the inner board And like the inner board, so like compress some of the powder down. And And try atomizing that and getting kind of the full melt pool.
31:45 Bartosz Kalicki: I I mean, as long as you don't put like pure powder in the Crucible, it should be fine.
31:51 Gage Erickson: OK.
31:52 Bartosz Kalicki: The problem with the pure powder is that very often it's kind of like melted, but each single particle doesn't really fully melt. It stays in form of a particle, so it's kind of like you have it all centered. Even though you are much higher in case of temperature than you should be. And still you don't really see the melt. But if you have some of the material already melted and. Then. How they can dissolve in the melt? It should work properly.
32:18 Sterling Baird: OK. OK. Gotcha. So we'll I think we'd like to try having the at least try one run where the powder is in the is in the Crucible, right. Like in this kind of like powder in this aluminum percible to see how that goes.
32:32 Bartosz Kalicki: Sure.
32:35 Sterling Baird: But if it doesn't like we can. We'd have to force that to work, but I.
32:37 Bartosz Kalicki: Yeah, yeah, we can use the extra time just to to run those kinds of experiments.
32:41 Sterling Baird: OK. Yeah. And then for mixing like I'm trying to, I should probably know the answer to this question, but. Is there induction mixing that happens?
32:58 Bartosz Kalicki: Yeah, in most in some. It's still nice to have.
32:58 Sterling Baird: Of the Of the yeah, yeah, I'll try.
33:03 Bartosz Kalicki: Master alloy whenever possible, but you can see that there is the mixing when we reach the temperature material is melted. It doesn't cut like heat up or continuously. It's going to kind of make this pulsation. That causes the whole whole melt to mix a bit. Master alloy whenever
33:06 Sterling Baird: Yeah. OK. OK. That makes sense That makes sense OK That makes sense OK I think That makes sense. OK, I think that.
33:23 Bartosz Kalicki: It's not something that I love to rely on, so like whenever possible I would say that having master alloy is generally better.
33:24 Sterling Baird: I think that covers my Oh yeah. Yeah. OK.
33:32 Bartosz Kalicki: But But if it's not like some, you know, critical addition of small amount that may melt may. If it's something with much higher melting point, there is a chance that it will kind of just like clump in one spot you know and not really get dissolved that well and.
33:33 Gage Erickson: And.
33:38 Sterling Baird: OK.
33:49 Bartosz Kalicki: So well mixed.
33:50 Sterling Baird: OK
33:51 Bartosz Kalicki: So maybe if you have like.
33:51 Sterling Baird: OK.
33:53 Bartosz Kalicki: Aluminium plus a bit of the master alloy that will definitely mix well.
33:58 Sterling Baird: Yeah. And would you recommend a general casting? Like, if we're gonna make our own master alloy from maybe stock powders. To do like a casting process for that.
34:12 Bartosz Kalicki: I mean, depending on what what you have available, you know using plasmark will usually be better even in case of powders that that if you have like an arc melter that is suitable for powders that would probably be easier because you could basically mix anything that way.
34:19 Sterling Baird: OK. OK. OK. OK. Yeah, that makes sense. Cool.
34:34 Bartosz Kalicki: Even if there was like a large melting point difference with the arc, you will have everything melted so.
34:43 Sterling Baird: OK, sounds good. I think that covers all my all my extra extra questions. So we're looking forward to having you.
34:50 Gage Erickson: So
34:51 Bartosz Kalicki: What?
34:52 Gage Erickson: So.
34:52 Sterling Baird: Oh yeah, good. Go ahead.
34:53 Gage Erickson: Just just on over the, the schedule again, was there a specific reason we decided to start on the 28th?
34:59 Sterling Baird: Oh, that New York.
35:02 Bartosz Kalicki: Yeah
35:02 Sterling Baird: He's.
35:02 Bartosz Kalicki: Yeah I Yeah, I mean, so as I understand, this is even better for you to go start 128 if possible. I hope just to make sure that I have the, you know, the two days free afterwards, because I may need to visit one more place on my way. So So that would definitely be preferable to go with 28 nine when 35 and then I may be able to squeeze something else on my trip.
35:32 Gage Erickson: You have. You're saying you have another responsibility like after the 30th on the 1st?
35:39 Bartosz Kalicki: But it would seem so that if I'm already in the states, I may have to visit one.
35:40 Sterling Baird: Pretty likely, yeah.
35:43 Bartosz Kalicki: I'm trying just to get the details but it seems that I may have to visit one more place on the way.
35:47 Gage Erickson: Yeah. OK, got you. OK, sounds good.
35:52 Bartosz Kalicki: But yeah, in case of your schedule, I will just adjust myself. So that
35:58 Gage Erickson: Yeah. So if it's not a big deal for me to be there on Monday, that's fine.
35:59 Bartosz Kalicki: So that.
36:02 Gage Erickson: I'm I'm completely open the whole rest of the week, so if if if it came down to that we did start on the the 29th and 30th and maybe the 1st. That I I'm completely free all those days. But if it's a big deal for me to be there on the 28th, then that's fine. You 20th to 30th.
36:18 Bartosz Kalicki: Yes. We will just cover the installation, put everything in place. I will do a very full training, prepare everything for for the I mean I will do the testing and prepare everything for the training. Take all the consumables from the boxes and just organize everything. It's mostly going to be this kind of work. I will want to make sure that it heats up fully. That's the coolant flow works.
36:48 Bartosz Kalicki: So So it's nothing very critical.
36:50 Sterling Baird: And.
36:51 Gage Erickson: OK, sounds good.
36:51 Sterling Baird: I think we'll I think we'll take videos and then Gage, you can if there are any videos that is like, oh, it'd be really good for you to see this before the Tuesday training. Then maybe that evening if you have time, then we watch some of those.
37:03 Gage Erickson: Yeah.
37:04 Bartosz Kalicki: Yeah, but you will also get access to like a website where we have videos.
37:05 Sterling Baird: That's. Yeah.
37:09 Bartosz Kalicki: Which just tell about Which just tell about the operation about like how to put assembly everything together, so you will also have access to that. So no worries.
37:19 Gage Erickson: Sounds good.
37:21 Sterling Baird: Yeah. Yeah. Thanks very much.
37:22 Bartosz Kalicki: OK then.
37:23 Sterling Baird: Looking forward to having Looking forward to having you here.
37:24 Bartosz Kalicki: Sure Sure Yep Sure. Yep. Let me know if you have any questions, anything to add extra things that you would like to cover and I will make sure that I'm ready for it.
37:34 Gage Erickson: Sounds good. Appreciate your bhartosh.
37:36 Sterling Baird: OK OK OK
37:37 Bartosz Kalicki: Hey
37:37 Sterling Baird: OK thanks
37:37 Bartosz Kalicki: Hey, thank you for the meeting.
37:38 Sterling Baird: OK. OK. Thanks for that. See you.
37:39 Bartosz Kalicki: That helps a lot.
37:40 Sterling Baird: Yeah
37:41 Bartosz Kalicki: See you.
37:41 Sterling Baird: Yeah, yeah.
37:42 Gage Erickson: You have a moment staring.
37:44 Sterling Baird: Yeah, yeah, I can sail. Yeah.
37:47 Gage Erickson: So. Was this? Was this was Was this the aluminum you were referring to that you Was this the aluminum you were referring to that you wanted to test?
37:52 Sterling Baird: No, we'll get some. Oh, actually, that's a good point. I was thinking of ordering from McMaster.
37:59 Gage Erickson: Uh.
38:01 Sterling Baird: Doing. A A. Either McMahon, probably McMaster to start out with and just trying to order some high the highest purity aluminum rod that we can from there. And then I guess the outer diameter would be 20. 20mm and then we'll probably it'll probably be good to talk with the machine shop folks if 20mm and then we'll probably it'll probably be good to talk with the machine shop folks if to see whether it. Is reasonable. Actually, no, I think. I think we should be fine, like going about 3 inches. About 3 inches deep into one of these.
38:36 Sterling Baird: One of these One of these rods. And then I guess we'll want to order.
38:42 Gage Erickson: OK.
38:43 Sterling Baird: Ideally a. The right size of rod that could be press fit into it. So I guess trying to get 2 diameters of of rods.
38:54 Gage Erickson: You're saying two different, two different diameters of aluminum rods. SO11 large 20mm diameter, one that could fit within the drill hole.
39:03 Sterling Baird: Yeah yeah that's right the drilled out The drilled out portion, yeah.
39:07 Gage Erickson: What's what's 002 cap it after you put the powder inside?
39:11 Sterling Baird: Basically, yeah.
39:11 Gage Erickson: Gotcha
39:12 Sterling Baird: And to compress the powder down to make it hopefully easier to easier to melt.
39:12 Gage Erickson: Gotcha. Yeah.
39:19 Sterling Baird: So.
39:20 Gage Erickson: Is that some? Is that something you'd like me to do? Is to find that or.
39:24 Sterling Baird: Actually, yeah, yeah. If you wouldn't mind.
39:27 Gage Erickson: OK.
39:27 Sterling Baird: One of my things is One of my things is I think we have some McMaster credentials on BYU VCL. And so you can just think about and say, hey, look at McMaster using the Raspberry Pi and find us the highest purity aluminum rods that are there and also. Like look at other suppliers in case there's something that's higher purity than that, so. Like look at other suppliers in case there's something that
39:51 Gage Erickson: Yeah.
39:53 Sterling Baird: I think that'll be it.
39:53 Gage Erickson: Sounds good Sounds good. I'll I'll query that.
39:56 Sterling Baird: OK.
39:56 Gage Erickson: It's saying that he said that powders don't mix very well within the atomizer. It's saying that he said that powders Don That's kinda. I was asking if. If, like we could, we could start melting it with the furnace open. In order to like stir it with something you know. But then I I didn't think about the fact that. The whole point of the enclosure is keep the oxygen out while you're melting it.
40:24 Sterling Baird: Yeah. Yeah, so. We. If it becomes a big issue with the powders not I mean like.
40:39 Gage Erickson: Can you hear me?
40:39 Sterling Baird: I I I I think we'll like. We'll see. Like we'll kinda see how things go if we need a. Like I I I think there's some options for US. One is that we we look at doing a vacuum.
40:53 Gage Erickson: Yeah.
40:55 Sterling Baird: Like a like doing a vacuum press. And so we actually really like press fit this thing and we're putting like a lot of hydraulic pressure to try to compact the powders and then potentially like a heated vacuum press. So we're actually like. Like we're not Like, we're not melting it, but we're like.
41:14 Gage Erickson: Ceiling it.
41:16 Sterling Baird: Yeah. Like kind of getting the particles to to adhere to each other a little bit more there's also.
41:21 Gage Erickson: Wonder if you do like friction.
41:23 Sterling Baird: Sorry, go ahead.
41:23 Gage Erickson: Stir welding friction. Stir welding something.
41:28 Sterling Baird: Yeah, or trying to get an arc mount to.
41:29 Gage Erickson: I I I I just know in that process. Oh yeah.
41:32 Sterling Baird: Oh sorry Oh, sorry. What were you saying?
41:34 Gage Erickson: Oh, I just say. I know in that section friction stir welding that it doesn't melt the metal, it just like heats it up enough that the molecules connect but anyways.
41:43 Sterling Baird: OK. Yeah, yeah, yeah. So. And then And then our backup plan would probably be going to. I guess there I guess there's a couple. Maybe a couple backup things we could do, but one would be going to University of Utah and barring some of the arc melting equipment there and trying to make our master alloys there with the powder mixture and then bringing it back, it would be really nice if we.
42:02 Gage Erickson: Hello.
42:12 Sterling Baird: Could get it to work out with powders. I think it would be.
42:17 Gage Erickson: Yeah, for real, well, I think. You know, if we, especially if we got like a high purity feedstock like this like if I know this isn't high purity, but if it was then I mean that's the that's the that's the the base of our allies are like majority of the allies gonna be like. Aluminum anyways.
42:34 Sterling Baird: Yeah.
42:35 Gage Erickson: And so you could you could put this in. Clip off for the amount you want and then have Clip off for the amount you want and then have pour the powder in after that. Instead of 'cause I mean like we got. We gotta. You saw the e-mail about the the quote from valent 2 kilograms of aluminum powder.
42:51 Sterling Baird: Oh no. How much was it?
42:53 Gage Erickson: Well then send me an actual number yet, because they wanted a bunch of papers signed.
42:57 Sterling Baird: Oh. Oh yeah. Yeah, sorry.
43:01 Gage Erickson: So but anyways, like maybe maybe we wouldn't wanna buy 2 kilograms of aluminum powder because we'd rather have a more solid-state. Version Version you know.
43:11 Sterling Baird: Oh yes, which means, yeah, yeah. And that. Yeah. So there's there's definitely some. I I think there's gonna be some I I think there's gonna be some trial and error and I think that's part of why it would be nice to have to do some of that trial and error while bartash's here.
43:27 Gage Erickson: Yeah.
43:28 Sterling Baird: It's kinda like with the expert.
43:31 Gage Erickson: We we got, we got all that stainless steel powder too. We could maybe test something with that. Oh, but we can't melt stainless steel, can we? I can't.
43:38 Sterling Baird: No, no. Yeah. Yeah, it's really.
43:40 Gage Erickson: I can't that.
43:41 Sterling Baird: It's really only copper and aluminum that we'd be doing with the induction induction Prunus, I think.
43:47 Gage Erickson: Gotcha. Well, copper has a pretty high melting point I think, but I guess not relative to most other things.
43:53 Sterling Baird: Yeah, it's lower than aluminum.
43:55 Gage Erickson: Oh really?
43:56 Sterling Baird: Feel it? That's basically, yeah, pretty sure. Yeah, all. So I'll go ahead and I'll probably get some issues either issues updated. Sorry, I got a bit too late. Got up way too early. Sorry I got a
44:16 Gage Erickson: Correct.
44:19 Sterling Baird: Yeah I'll probably get you tagged on some Yeah, I'll probably get you tagged on some issues. But I think the main things were not not in like in this order of priority, but just the things that come to mind like the dehumidifier if we could try to get that running. Ordering the two high purity aluminum rods, like trying to find find the ones that we want and and ordering those. You'll talk with. Sorry. With Nick about gas. Like enter gas stuff.
44:55 Sterling Baird: I think I think they'll still it. It would still be good to try to look into like the glove box, like enclosure stuff. See if maybe there's one that we can get for a few grand.
45:05 Gage Erickson: Uh-huh.
45:05 Sterling Baird: Up Up to like Up to like four or five Up to like four or five grand for that. And. Excuse me. Yeah. Anyway, I think both. Thanks Thanks for managing all of this so so many things to get it going.
45:23 Gage Erickson: What? Yeah. Yeah, no worries. Maybe. I I'll make sure I understood Bartos properly.
45:37 Sterling Baird: Mm-hmm.
45:38 Gage Erickson: For. Our connect Our connection Our connection, it sounded like. From what I understand, these these are half inch and these are going to connect the heat exchanger my cameras and turn around with it. These half inch tubes we're gonna use to connect to the back of the heat exchanger here.
45:57 Sterling Baird: Oh.
46:02 Gage Erickson: And so we need to. I'll work with Dave to get.
46:04 Sterling Baird: Mm-hmm yeah Yeah.
46:08 Gage Erickson: What do they
46:08 Sterling Baird: Yes.
46:09 Gage Erickson: What do they? What conversions or whatever?
46:11 Sterling Baird: Yeah. Adapters. Yeah, just some some adapters.
46:13 Gage Erickson: And adapters and then also to adapters for that.
46:17 Sterling Baird: Yeah.
46:18 Gage Erickson: But it sounded like Bartos was bringing a a tube or pipe for another part. I just I just can't remember what. That was.
46:27 Sterling Baird: Yeah, I have. I I have I have a transcript so I could try to link the transcript to see if we.
46:37 Gage Erickson: That's a good idea.
46:37 Sterling Baird: Track that what he was talking about there. I didn't record the meeting, but I anyway this there's a transcript here so.
46:47 Gage Erickson: Herbert.
46:48 Sterling Baird: And then I'm now that I'm thinking about it. It might. I think it would also be worth maybe trying to have somebody go up to University of Utah with one of these powder mixtures and try to make a make a master alloy. Or or sorry me. Yeah, like arc melts. Some of the powders with. With some aluminum and kinda make like just make our own like or even if we just took the ALS I10MG and just put that powder in and arc melted it just to see you like kind of what our options are like it would be really cool.
47:29 Sterling Baird: If If before Barta left. Bartosh left. That we had a. Some sample that we prepped get atomized. That if that makes sense. So kinda like our first half like our first experiment.
47:48 Gage Erickson: Yeah. And I think it'd be good too. You know, since we already had the ALS I10MG to to, to melt that into an alloy and then atomize ourselves to compare. You know what? What does that look like versus what we can do with ours?
48:01 Sterling Baird: Yeah, yeah.
48:04 Gage Erickson: Was there another? Was there another specific alloy you wanted to do that with it at the University of Utah?
48:10 Sterling Baird: You know, honestly, if we get some of that scandium and Oh no, no, the scandium's gonna take a while. So not on the scanium, but maybe.
48:16 Gage Erickson: Yeah.
48:19 Sterling Baird: So actually that that's it, if we if we do get everything we need to make ALS site. Sorry ALS I10MG on our own, not from the like the commercial powder for ALS I10MG that would be. That would be cool. So like.
48:39 Gage Erickson: Yeah.
48:39 Sterling Baird: Yeah. So maybe maybe in some sense it's like. Yeah, I think. I think it's her to university I think it's her to University of Utah seeing if we can use one of their arc filters. This would be through Taylor Sparks. I know it has an an arc melter. I'm trying to get that. As some stock As some stock material to bring in that could be related and then we'll probably we might just be making a lot of trips to the chem store for containers and stuff and Potter, but oh that's right.
49:16 Gage Erickson: We got those, those chemical, those blue chemical cabinet things that we could put powders in if you want.
49:23 Sterling Baird: Oh, yeah. Yeah, that's right. And I think we probably we wanna get a whole bunch of desiccant. Including desiccant, that's meant like kind of kosher to throw in a container as well.
49:37 Gage Erickson: I I've got, so I bought a package like some small desk and bags. Can you see that?
49:44 Sterling Baird: OK. Oh, I see. OK.
49:47 Gage Erickson: This is for master McMaster, so here's like one packets. I don't know if that's big enough, but we've got several of these.
49:50 Sterling Baird: Oh that's right OK Oh, that's right. OK. Yeah. And then I think we just wanna make sure that what like 'cause, it's usually silica gel. Make sure that that's not. Contaminating the like, we might just wanna look a couple cloud pings on like silica or or like sorry desiccants that. Don't like, wouldn't contaminate the powders that we're working with, like in the container. We might wanna do a little bit. Look into that. As well so but I think.
50:29 Gage Erickson: Ping.
50:31 Sterling Baird: Yeah, I think that maybe covers comes our basis.
50:32 Gage Erickson: Yeah, go ahead. God forbid. Uh. So ping cloud to check if silicon desk can. Will contain our Will contain our patterns.
50:49 Sterling Baird: Oh yeah, and silica, silicon oxide. It's usually what the.
50:53 Gage Erickson: So.
50:56 Sterling Baird: Yeah, the desk is.
51:03 Gage Erickson: Powers. It be really nice if we could like go to somewhere like valenet or somewhere in industry to see how they handle their powders and procedures they have, because then we could then we could copy or mimic those and then we're not just like guessing if we're doing too.
51:16 Sterling Baird: Yeah.
51:22 Gage Erickson: Much or not enough or not paying attention specifically.
51:23 Sterling Baird: Yeah. Yeah, yeah. I agree with a development would be pretty good I agree with a development would be pretty good I think.
51:31 Gage Erickson: Is Valmet the closest one? That's like in the industry.
51:35 Sterling Baird: Yeah, especially for aluminum. Which Which there are so many things about the workflow like safety and handling wise that would be specific to aluminum that that would be. That That would probably be our best bet That would probably be our best bet to go over there.
51:51 Gage Erickson: Yeah. How would how would organize a trip like that? Work. Would that be universally funded, or that come from lab funds or?
52:00 Sterling Baird: Oh, yeah, yeah, it would be. It would be lab funded. It would come from lab funds and it could be like you could honestly be a road trip or or flight, you know it's. With like a car rental from BYU, depending on how many people like if we're gonna have like three to five people go down and I think doing a car rental would make the most sense. Otherwise, like a flight would be be fine too. It was just like one or two people.
52:33 Gage Erickson: OK. Is that is that something you wanna think about right now or come back to in like a month from now or?
52:35 Sterling Baird: Hold on.
52:36 Gage Erickson: Is
52:41 Sterling Baird: Probably probably like a month from now, but I I I think it's well. It it might be worth just getting on a on a call with them initially to say just to kind of walk them through our procedures of what we're doing and and in fact like a kind like a video, maybe like a prerecorded video that we send to them. It it might be worth just getting on a on a call with them initially And just say like, hey, you know, could you look through what we're kinda thinking in terms of our our workflows and just let us know if anything seems kind of out of place or overkill or? I think I think I I think I think that would be a good. Starting point.
53:19 Sterling Baird: For that and pretty good use of use of time, just like. If we had kind of our like our safety video. You will
53:28 Gage Erickson: Yeah.
53:29 Sterling Baird: You will or just start like our workflow. Workflow described. Workfl Workflow descri So that or.
53:42 Gage Erickson: Call with them. Remind this all down South? Forget.
53:47 Sterling Baird: Yeah.
53:53 Gage Erickson: Talk about safety. And. OK, cool. Very good. OK. So I'll I'll talk to Barry to figure out how we get this dehumidifier on because I don't know.
54:13 Sterling Baird: Yeah.
54:13 Gage Erickson: I'll talk to Nick about making sure we get five in argon. I'll work with Dave for I'll work with Dave for the pipe hookups and all that. If you'll send me the important part of the transcript for that.
54:21 Sterling Baird: Yeah.
54:26 Gage Erickson: And then.
54:26 Sterling Baird: Yeah.
54:29 Gage Erickson: Do you have a specific like is there a? Do you know? Do you want me to reach out to Taylor Sparks or? Oh do
54:36 Sterling Baird: Oh, for the arc melting.
54:36 Gage Erickson: Oh do you want Oh, do you want to?
54:38 Sterling Baird: Actually, yeah, yeah. If you wouldn't mind, just make sure to CC me, like, hey, you know.
54:43 Gage Erickson: Just send him an e-mail.
54:45 Sterling Baird: Yeah, yeah.
54:46 Gage Erickson: OK.
54:48 Sterling Baird: Good Good I
54:49 Gage Erickson: And I'll just ask him.
54:49 Sterling Baird: Good. I'm getting better at delegating this ever so slightly ever so slightly better.
54:53 Gage Erickson: Good. That's an important skill, especially in running a business.
54:58 Sterling Baird: Yeah. Yeah, no kidding. So. Yeah Yeah.
55:03 Gage Erickson: So yeah, I'll just. I'll just e-mail them saying, hey Sterling and I want to do some arc melting of some ALS I10MG powder. This could This could. We could we talk about that? What your thoughts are on that? I'm doing something like that maybe?
55:19 Sterling Baird: Yeah, like is there. Is there a student like? Does it seem feasible you know to to do by the like 28 or 29th so we could test it with our atomizer. If so, like is there a student we could get connected with to to help us do that run within? Something like that. And then basically whatever e-mail you send don't be like I might just reply as well and just like add any extra bits of FOI think is text.
55:52 Gage Erickson: OK, perfect. That makes it easy.
55:57 Sterling Baird: Yeah.
55:58 Gage Erickson: Student see. OK. So that and then I'll ask Claude about the. McMaster high purity aluminum rods 20mm and then a smaller one.
56:17 Sterling Baird: Mm-hmm.
56:18 Gage Erickson: I'll figure out a good ratio for that and then also ask Claud about the silica oxide that you can't for this little containment contaminator powders. Yeah. Is that everything?
56:27 Sterling Baird: Yeah. Yeah yeah I think that's everything Yeah. Yeah, I think that's everything.
56:31 Gage Erickson: Sweet. What is the productive meeting?
56:34 Sterling Baird: Yeah, yeah, I agreed. OK, OK. Thanks Gage.
56:38 Gage Erickson: OK. Thank you see ya
56:40 Sterling Baird: I appreciate it. Thanks for that

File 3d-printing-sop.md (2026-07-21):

# 3D Printing SOP — Vertical Cloud Lab

Standard operating procedure for the lab's FDM 3D printers, including
**multi-material PLA + TPU** prints on the **Bambu Lab H2D**.

> **Scope:** This is a working resource for lab members. Edit it freely as we
> learn what works. Anything in _[square brackets]_ is a placeholder to be
> filled in with our specific hardware, contacts, or lab conventions.

- **Printer(s):** Bambu Lab H2D _(add others here as acquired)_
- **Slicer:** Bambu Studio _(recommended; OrcaSlicer is a compatible alternative)_
- **Lab location:** _[Lab #, Building]_
- **Primary contact:** _[name / email]_
- **Related:** [tensegrity-optimization #37](https://github.com/vertical-cloud-lab/tensegrity-optimization/issues/37)

---

## 1. Safety first

- **Read the [BYU Engineering SOP template](byu-engineering-sop-template.md)** and any
  BYU lab-safety documents in this repo before operating equipment unsupervised.
- **Hot surfaces.** The nozzles (up to ~300 °C) and heated bed (up to ~110 °C)
  cause burns. Do not reach into the build chamber while printing or immediately
  after. Let parts and the bed cool before removing.
- **Ventilation.** FDM printing emits ultrafine particles and VOCs. Keep the
  printer's enclosure closed during printing and run in a ventilated area. The
  H2D has a built-in air filter — check that the carbon filter is installed and
  not expired.
- **Moving parts.** Keep hands, hair, and tools clear of the gantry, toolhead,
  and cutter while the machine is powered and homing/printing.
- **Electrical & fire.** Do not leave long prints fully unattended overnight
  without following the lab's remote-monitoring rule below. Know where the
  nearest fire extinguisher and emergency stop are: _[location]_.
- **Tools.** Use the flush cutters, scraper, and pliers carefully; the bed
  scraper is sharp. Never use a metal scraper that can gouge the PEI plate.

**Emergency contacts** (from the BYU SOP template):

- University Police: 801-422-2222
- Risk Management: 801-422-4468
- College Health & Safety Officer: 801-422-6589

---

## 2. Materials overview

| Material | Typical nozzle | Bed  | Enclosure | Notes |
| --- | ---: | ---: | --- | ----- |
| **PLA**  | 190–220 °C | 35–55 °C | Open OK, door ajar to avoid heat creep | Easy, rigid, low warp. Keep dry-ish. |
| **TPU** (e.g., 95A) | 220–240 °C | 35–45 °C | Open OK | Flexible. **Print slow** and direct-drive only. Very moisture-sensitive. |

- **Verify the manufacturer's recommended temperatures** on the spool and in the
  Bambu Studio filament profile — the ranges above are starting points.
- **Dry filament matters.** TPU and, to a lesser extent, PLA absorb moisture,
  which causes stringing, popping, and weak layers. Dry TPU before critical
  prints _(≈ 60–70 °C for 6–12 h in a filament dryer / low oven)_. Store spools
  with desiccant.

### Why the H2D is well suited to PLA + TPU

The H2D has **two independent nozzles (dual extruder)**. This is the preferred
way to combine PLA and TPU: each material has its own direct-drive path, so soft
TPU never has to travel through a shared Bowtube/AMS buffer where it tends to
buckle. Assign PLA to one nozzle and TPU to the other.

> **Avoid running TPU through the AMS** unless using an AMS/profile explicitly
> rated for that TPU. Soft filaments jam in the AMS feed path. Feed TPU from an
> external spool holder into the direct-drive nozzle.

---

## 3. Before you print (checklist)

- [ ] Build plate is the right type for the material (textured PEI is a good
      default for both PLA and TPU) and is **clean** — wash with dish soap +
      water or wipe with IPA; avoid touching the surface with bare fingers.
- [ ] Correct filament loaded in the correct nozzle/slot, and the slicer's
      filament assignment matches physically what's loaded.
- [ ] Filament is dry (especially TPU) and feeding freely without tangles.
- [ ] Nozzles are clean; no stuck debris or "boogers" on the tips.
- [ ] Firmware and Bambu Studio are reasonably up to date.
- [ ] You have logged your print / reserved the machine per lab convention:
      _[sign-up sheet / calendar link]_.

---

## 4. Slicing workflow (Bambu Studio)

1. **Import geometry.** Open your STL/STEP/3MF in Bambu Studio and select the
   **Bambu Lab H2D** printer profile.
2. **Assign materials to nozzles.** In a multi-material project, map each object
   (or each modifier/part) to a filament: **PLA → nozzle 1, TPU → nozzle 2**
   (or per lab convention). Confirm the filament profiles' temperatures.
3. **Choose a base profile.** Start from a standard 0.20 mm profile and adjust.
   Save lab-tuned profiles back into this repo or a shared drive when you find
   good settings _(link: [placeholder])_.
4. **Slice, then inspect the preview.** Step through layers to check the
   material transitions, seams, and any purge/wipe towers.
5. **Estimate & sanity check.** Review time and filament estimates before
   committing to long prints.

### Suggested starting settings

| Setting | PLA | TPU |
| --- | --- | --- |
| Layer height | 0.20 mm | 0.20 mm |
| Print speed (outer walls) | 100–200 mm/s | **15–30 mm/s** |
| Retraction | Default | Minimal / short |
| Flow (cooling) fan | High | Low–medium |
| Supports | As needed | Prefer designing to avoid; TPU supports are hard to remove |

> **Multi-material specifics:** expect a **purge/prime tower** and material-change
> purging. This wastes some filament but keeps colors/materials from bleeding.
> For a first test, the tensegrity workflow suggests something as simple as
> **alternating a few layers of TPU and PLA** to validate adhesion and the
> tool-change sequence before attempting a full part.

---

## 5. Running the print

1. **Send** the job via LAN / Bambu Studio / SD card (per lab preference).
2. **Watch the first layer.** This is the single most important step — confirm
   good bed adhesion and no nozzle collisions. Cancel and re-level/re-clean if
   the first layer looks poor.
3. **Confirm each nozzle deposits** on its first use in a multi-material job.
4. **Monitoring:** Enable the printer's camera and remote monitoring. Follow the
   lab rule for unattended prints: _[e.g., "prints > X hours require remote
   monitoring + notify #channel"]_.

### PLA + TPU bonding notes

- PLA and TPU do **not** chemically weld strongly. For durable multi-material
  parts, design **mechanical interlocks** (dovetails, holes/pockets the second
  material flows into, overlapping perimeters) rather than relying on a flat
  interface.
- Increasing interface overlap and slightly higher temperature at the boundary
  layers can improve adhesion — tune experimentally and record results.

---

## 6. After the print

- [ ] Let the bed cool; flex the plate to release the part (textured PEI).
- [ ] Remove purge/prime tower and supports; dispose of scrap in _[waste bin]_.
- [ ] Clean the plate and return it to the printer.
- [ ] Unload TPU if the next user needs the nozzle, or leave loaded per lab
      convention. Store TPU with desiccant.
- [ ] Wipe down the work area and return tools.
- [ ] Note anything odd (jams, failures, low filament) in _[log / issue tracker]_.

---

## 7. Troubleshooting

| Symptom | Likely cause | Try |
| --- | --- | --- |
| First layer not sticking | Dirty/greasy plate, nozzle too high | Clean plate, re-level, lower Z offset slightly |
| TPU stringing / popping | Wet filament | Dry the TPU; reduce speed |
| TPU jam / grinding | Fed through AMS or too fast; retraction too high | Use direct-drive/external spool, slow down, reduce retraction |
| Layers separating (delamination) | Temp too low, drafts, moisture | Raise nozzle temp, close enclosure, dry filament |
| Multi-material color bleed | Insufficient purge | Increase purge volume / prime tower size |
| PLA/TPU interface splits | No mechanical bond | Redesign with interlocking geometry, increase overlap |
| Clogged nozzle | Debris, mixed materials, heat creep | Cold pull / hot clean per Bambu Lab guide |

---

## 8. References & resources

- Bambu Lab H2D user manual and wiki — _[add link]_
- Bambu Studio documentation — _[add link]_
- TPU printing guide (Bambu Lab) — _[add link]_
- BYU Engineering Lab Safety / Chemical Hygiene Plan — see PDFs in this repo
- Add tutorials/videos you found helpful here as you go:
  - _[link + one-line note]_

---

_Maintained by the Vertical Cloud Lab. Please open a PR to improve this SOP._

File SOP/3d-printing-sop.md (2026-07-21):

# 3D Printing SOP — Vertical Cloud Lab

Standard operating procedure for the lab's FDM 3D printers, including
**multi-material PLA + TPU** prints on the **Bambu Lab H2D**.

> **Scope:** This is a working resource for lab members. Edit it freely as we
> learn what works. Anything in _[square brackets]_ is a placeholder to be
> filled in with our specific hardware, contacts, or lab conventions.

- **Printer(s):** Bambu Lab H2D _(add others here as acquired)_
- **Slicer:** Bambu Studio _(recommended; OrcaSlicer is a compatible alternative)_
- **Lab location:** _[Lab #, Building]_
- **Primary contact:** _[name / email]_
- **Related:** [tensegrity-optimization #37](https://github.com/vertical-cloud-lab/tensegrity-optimization/issues/37)

---

## 1. Safety first

- **Read the [BYU Engineering SOP template](byu-engineering-sop-template.md)** and any
  BYU lab-safety documents in this repo before operating equipment unsupervised.
- **Hot surfaces.** The nozzles (up to ~300 °C) and heated bed (up to ~110 °C)
  cause burns. Do not reach into the build chamber while printing or immediately
  after. Let parts and the bed cool before removing.
- **Ventilation.** FDM printing emits ultrafine particles and VOCs. Keep the
  printer's enclosure closed during printing and run in a ventilated area. The
  H2D has a built-in air filter — check that the carbon filter is installed and
  not expired.
- **Moving parts.** Keep hands, hair, and tools clear of the gantry, toolhead,
  and cutter while the machine is powered and homing/printing.
- **Electrical & fire.** Do not leave long prints fully unattended overnight
  without following the lab's remote-monitoring rule below. Know where the
  nearest fire extinguisher and emergency stop are: _[location]_.
- **Tools.** Use the flush cutters, scraper, and pliers carefully; the bed
  scraper is sharp. Never use a metal scraper that can gouge the PEI plate.

**Emergency contacts** (from the BYU SOP template):

- University Police: 801-422-2222
- Risk Management: 801-422-4468
- College Health & Safety Officer: 801-422-6589

---

## 2. Materials overview

| Material | Typical nozzle | Bed  | Enclosure | Notes |
| --- | ---: | ---: | --- | ----- |
| **PLA**  | 190–220 °C | 35–55 °C | Open OK, door ajar to avoid heat creep | Easy, rigid, low warp. Keep dry-ish. |
| **TPU** (e.g., 95A) | 220–240 °C | 35–45 °C | Open OK | Flexible. **Print slow** and direct-drive only. Very moisture-sensitive. |

- **Verify the manufacturer's recommended temperatures** on the spool and in the
  Bambu Studio filament profile — the ranges above are starting points.
- **Dry filament matters.** TPU and, to a lesser extent, PLA absorb moisture,
  which causes stringing, popping, and weak layers. Dry TPU before critical
  prints _(≈ 60–70 °C for 6–12 h in a filament dryer / low oven)_. Store spools
  with desiccant.

### Why the H2D is well suited to PLA + TPU

The H2D has **two independent nozzles (dual extruder)**. This is the preferred
way to combine PLA and TPU: each material has its own direct-drive path, so soft
TPU never has to travel through a shared Bowtube/AMS buffer where it tends to
buckle. Assign PLA to one nozzle and TPU to the other.

> **Avoid running TPU through the AMS** unless using an AMS/profile explicitly
> rated for that TPU. Soft filaments jam in the AMS feed path. Feed TPU from an
> external spool holder into the direct-drive nozzle.

---

## 3. Before you print (checklist)

- [ ] Build plate is the right type for the material (textured PEI is a good
      default for both PLA and TPU) and is **clean** — wash with dish soap +
      water or wipe with IPA; avoid touching the surface with bare fingers.
- [ ] Correct filament loaded in the correct nozzle/slot, and the slicer's
      filament assignment matches physically what's loaded.
- [ ] Filament is dry (especially TPU) and feeding freely without tangles.
- [ ] For TPU, the filament has been dried appropriately; if humidity is not
      below about 8% RH, run a dry cycle at 70–75 °C for 12 h (or until the
      filament is dry) before printing.
- [ ] Nozzles are clean; no stuck debris or "boogers" on the tips.
- [ ] Firmware and Bambu Studio are reasonably up to date.
- [ ] You have logged your print / reserved the machine per lab convention:
      _[sign-up sheet / calendar link]_.

### TPU-specific setup on the H2D

- Before switching to TPU, verify the active nozzle is clean and the filament
  path is clear. If needed, heat the nozzle to about 180 °C, wipe away soft
  residue, and allow it to cool before continuing.
- Confirm TPU is loaded into the intended direct-drive nozzle and that the path
  is feeding smoothly. Avoid routing TPU through the AMS unless the filament
  profile specifically supports it.
- If TPU is not already loaded, use the printer's Load function and feed the
  filament through the rear loading path or TPU assist path until it begins to
  extrude. If it was already loaded, verify that it still feeds freely.
- For tall, thin, or small TPU parts, consider a raft or glue stick for better
  adhesion and keep the print area clear of stray filament purge.

---

## 4. Slicing workflow (Bambu Studio)

1. **Import geometry.** Open your STL/STEP/3MF in Bambu Studio and select the
   **Bambu Lab H2D** printer profile.
2. **Assign materials to nozzles.** In a multi-material project, map each object
   (or each modifier/part) to a filament: **PLA → nozzle 1, TPU → nozzle 2**
   (or per lab convention). Confirm the filament profiles' temperatures.
3. **Choose a base profile.** Start from a standard 0.20 mm profile and adjust.
   Save lab-tuned profiles back into this repo or a shared drive when you find
   good settings _(link: [placeholder])_.
4. **Slice, then inspect the preview.** Step through layers to check the
   material transitions, seams, and any purge/wipe towers.
5. **Estimate & sanity check.** Review time and filament estimates before
   committing to long prints.

### TPU-oriented slicer notes

- For tall, thin, or small TPU parts, generate a raft in Bambu Studio or use a
  glue stick to improve first-layer adhesion.
- If supports are necessary for TPU, prefer PLA-only support material, paint
  supports manually, and keep them limited to the build plate when possible.
- Disable TPU flushing into supports and avoid generating support interfaces on
  the part itself unless there is no practical alternative.
- If the print is tall or unstable, keep the print speed conservative and watch
  for wobble or skipped layers during the first few layers.

### Suggested starting settings

| Setting | PLA | TPU |
| --- | --- | --- |
| Layer height | 0.20 mm | 0.20 mm |
| Print speed (outer walls) | 100–200 mm/s | **15–30 mm/s** |
| Retraction | Default | Minimal / short |
| Flow (cooling) fan | High | Low–medium |
| Supports | As needed | Prefer designing to avoid; TPU supports are hard to remove |

> **Multi-material specifics:** expect a **purge/prime tower** and material-change
> purging. This wastes some filament but keeps colors/materials from bleeding.
> For a first test, the tensegrity workflow suggests something as simple as
> **alternating a few layers of TPU and PLA** to validate adhesion and the
> tool-change sequence before attempting a full part.

---

## 5. Running the print

1. **Send** the job via LAN / Bambu Studio / SD card (per lab preference).
2. **Watch the first layer.** This is the single most important step — confirm
   good bed adhesion and no nozzle collisions. Cancel and re-level/re-clean if
   the first layer looks poor.
3. **Confirm each nozzle deposits** on its first use in a multi-material job.
4. **Monitoring:** Enable the printer's camera and remote monitoring. Follow the
   lab rule for unattended prints: _[e.g., "prints > X hours require remote
   monitoring + notify #channel"]_.

### PLA + TPU bonding notes

- PLA and TPU do **not** chemically weld strongly. For durable multi-material
  parts, design **mechanical interlocks** (dovetails, holes/pockets the second
  material flows into, overlapping perimeters) rather than relying on a flat
  interface.
- Increasing interface overlap and slightly higher temperature at the boundary
  layers can improve adhesion — tune experimentally and record results.

---

## 6. After the print

- [ ] Let the bed cool; flex the plate to release the part (textured PEI).
- [ ] Remove purge/prime tower and supports; dispose of scrap in _[waste bin]_.
- [ ] Clean the plate and return it to the printer.
- [ ] Unload TPU if the next user needs the nozzle, or leave loaded per lab
      convention. Store TPU with desiccant.
- [ ] Wipe down the work area and return tools.
- [ ] Note anything odd (jams, failures, low filament) in _[log / issue tracker]_.

---

## 7. Troubleshooting

| Symptom | Likely cause | Try |
| --- | --- | --- |
| First layer not sticking | Dirty/greasy plate, nozzle too high | Clean plate, re-level, lower Z offset slightly |
| TPU stringing / popping | Wet filament | Dry the TPU; reduce speed |
| TPU jam / grinding | Fed through AMS or too fast; retraction too high | Use direct-drive/external spool, slow down, reduce retraction |
| Layers separating (delamination) | Temp too low, drafts, moisture | Raise nozzle temp, close enclosure, dry filament |
| Multi-material color bleed | Insufficient purge | Increase purge volume / prime tower size |
| PLA/TPU interface splits | No mechanical bond | Redesign with interlocking geometry, increase overlap |
| Clogged nozzle | Debris, mixed materials, heat creep | Cold pull / hot clean per Bambu Lab guide |

---

## 8. References & resources

- Bambu Lab H2D user manual and wiki — _[add link]_
- Bambu Studio documentation — _[add link]_
- TPU printing guide (Bambu Lab) — _[add link]_
- BYU Engineering Lab Safety / Chemical Hygiene Plan — see PDFs in this repo
- Add tutorials/videos you found helpful here as you go:
  - _[link + one-line note]_

---

_Maintained by the Vertical Cloud Lab. Please open a PR to improve this SOP._

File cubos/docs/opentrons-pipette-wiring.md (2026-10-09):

# Opentrons pipette → TMC2209 → Arduino wiring, checked against the firmware

Written 2026-09-01 while diagnosing "nothing happens on the pipette — no buzzing,
the plunger never moves" on the CubXL. Revised 2026-09-08: §3 corrected (pin 6 →
GND *is* on the Cubware diagram) and extended with the connector-orientation
check, and §4 added.

**Where the Ursa documentation lives.** There is exactly one Ursa-authored
pipette wiring source —
[`Cubware/documentation/opentrons-pipette-setup.md`](https://github.com/Ursa-Laboratories/Cubware/blob/main/documentation/opentrons-pipette-setup.md)
and its `images/PipetteControl.png`. (`images/ArduinoCircuitDiagram_v3.png` in the
same folder is the capper/lights circuit, referenced from
`vial-capper-decapper-build.md`; it has nothing to do with the pipette. Nothing in
CubOS, PANDA-CUB, Zoo or BU-Configs documents this wiring.) That page delegates
onward: *"The legacy PANDA-BEAR wiring docs point to the external
BU-KABlab/PANDA_Arduino repository for firmware source, pin assignments, and
installation instructions."* `PANDA_Arduino` in turn carries a vendored copy of
the science-jubilee OT2 pipette tool doc at `src/pipette_tool.md`, and *that*
project is where the authoritative 10-pin material actually is.

The wiring diagram in Cubware
([`documentation/opentrons-pipette-setup.md`](https://github.com/Ursa-Laboratories/Cubware/blob/main/documentation/opentrons-pipette-setup.md)
→ `images/PipetteControl.png`) does **not** match the pin map in the firmware that
Arduino is running. The pipette side of the diagram is right; the Arduino side is
shifted by one analog pin on all four driver-control lines, and the pin the
firmware actually drives as ENABLE is not connected to anything.

Everything below is read out of source, not inferred from behaviour. Sources:

| what | where |
|---|---|
| firmware pin map + constants | [`BU-KABlab/PANDA_Arduino` `include/Pipette.h`](https://github.com/BU-KABlab/PANDA_Arduino/blob/main/include/Pipette.h) |
| firmware step/home/aspirate logic | [`src/Pipette.cpp`](https://github.com/BU-KABlab/PANDA_Arduino/blob/main/src/Pipette.cpp) |
| driver library | [`janelia-arduino/TMC2209`](https://github.com/janelia-arduino/TMC2209) `@^10.1.0`, pinned in `platformio.ini` |
| OT-2 10-pin ribbon pinout | the Jubilee OT2 pipette tool doc, [`src/pipette_tool.md`](https://github.com/BU-KABlab/PANDA_Arduino/blob/main/src/pipette_tool.md) §"Wiring Harness Assembly" |
| **which physical hole is pin 1** | [`science-jubilee` `tool_library/OT2_pipette/assembly_docs/OT2_Wiring_Diagram.pdf`](https://github.com/machineagency/science-jubilee/blob/main/tool_library/OT2_pipette/assembly_docs/OT2_Wiring_Diagram.pdf) — a photograph of the pipette's own header with each wire on its hole |
| ribbon conductor numbering | [`_static/ribbon_to_hookup_wiring.png`](https://github.com/machineagency/science-jubilee/blob/main/docs/building/_static/ribbon_to_hookup_wiring.png) |
| breakout | [Adafruit 6121](https://www.adafruit.com/product/6121) — motor supply 5–29 VDC, VDD 3–5 V, **current set by an onboard potentiometer** |
| breakout schematic | [`adafruit/Adafruit-TMC2209-Breakout-PCB`](https://github.com/adafruit/Adafruit-TMC2209-Breakout-PCB) — Eagle `.sch`; read directly from 2026-09-26 (§22) |
| driver datasheet | [TMC2209 rev 1.09](https://github.com/janelia-arduino/TMC2209/blob/main/datasheet/TMC2209_datasheet_rev1.09.pdf) (janelia mirror of Analog Devices' PDF) — `DIAG` logic §15.4, short detection §15.2 and §20.2 |

Cubware's own text flags the whole page as provisional: *"the OT2 pipette hardware
path has not yet been validated on the physical machine in this checkout. Treat
every position, model constant, and serial command as a commissioning value."*

## 1. The firmware's pin map

```c
// include/Pipette.h
#define PIPETTE_LIMIT_PIN 9 // Limit switch for homing
#define RX_PIN 14           // SoftwareSerial RX pin (not connected but required)
#define TX_PIN 15           // SoftwareSerial TX pin to TMC2209 RX
#define STEP_PIN 16         // Step pin
#define DIR_PIN 17          // Direction pin
#define ENABLE_PIN 18       // Enable pin (optional)
```

On an Arduino Uno the analog pins carry digital numbers 14–19, so
`A0=14, A1=15, A2=16, A3=17, A4=18, A5=19`. Substituting:

| firmware symbol | value | Uno pin | goes to |
|---|---|---|---|
| `RX_PIN` | 14 | **A0** | nothing — SoftwareSerial RX, "not connected but required" |
| `TX_PIN` | 15 | **A1** | TMC2209 **UART** (PDN_UART) |
| `STEP_PIN` | 16 | **A2** | TMC2209 **STEP** |
| `DIR_PIN` | 17 | **A3** | TMC2209 **DIR** |
| `ENABLE_PIN` | 18 | **A4** | TMC2209 **EN** |
| `PIPETTE_LIMIT_PIN` | 9 | **D9** | pipette limit switch |

No other module in the firmware claims any of these — the capper/lights use
D3 (`NEOPIXEL_RING_PIN`), D4 (`LINEBREAK_SENSOR_PIN`), D5 and D6. There is no pin
conflict.

## 2. The diagram vs. the firmware

| signal | **firmware wants** | **diagram shows** | |
|---|---|---|---|
| TMC2209 `UART` | **A1** | A0 | ❌ A0 is the SoftwareSerial **RX** — the firmware never transmits on it |
| TMC2209 `STEP` | **A2** | A1 | ❌ A1 is the UART **TX** |
| TMC2209 `DIR` | **A3** | A2 | ❌ A2 is **STEP** |
| TMC2209 `EN` | **A4** | A3 | ❌ A3 is **DIR** |
| TMC2209 `GND` | GND | GND | ✅ |
| TMC2209 `VDD` | 5 V | 5 V | ✅ |
| limit switch signal | **D9** | D9 | ✅ |

Every driver-control line is one analog pin low, and **A4 appears nowhere in the
diagram**. What each one does if you build it as drawn:

**`EN` on A3 ⇒ the direction bit switches the driver on and off.** TMC2209 `EN`
is active-low. `moveTo()` does `digitalWrite(DIR_PIN, isMovingDown ? HIGH : LOW)`,
so the driver would be energised for one direction of travel and completely dead
for the other.

> **Correction, 2026-09-01.** Earlier revisions of this document, and the PR
> comments of 2026-08-31 and 2026-09-01, offered this as the explanation for the
> plunger only moving one way. **It is not.** The one-way behaviour is a
> *firmware* gate on the limit-switch reading — see §3 below, which quotes the
> line — and it is visible at the serial port as a flat ~0.11 s refusal, which an
> `EN` fault could never produce (the firmware does not read `EN` back). `EN` on
> A3 is still wrong and still needs moving to A4; it just is not what caused the
> one-way symptom.

**`UART` on A0 ⇒ the driver is never configured.** The firmware's
`setupMotor()` calls `setRunCurrent(50)`, `setHoldCurrent(30)`,
`setMicrostepsPerStep(16)`, `enableStealthChop()`, `enableCoolStep()` and
`enable()` — all of which are UART register writes. It never calls
`setHardwareEnablePin()`, so in the library `enable()` is UART-only:

```cpp
void TMC2209::enable() {
  if (hardware_enable_pin_ >= 0) { digitalWrite(hardware_enable_pin_, LOW); }  // never: default -1
  chopper_config_.toff = toff_;
  writeStoredChopperConfig();                                                  // UART
}
```

With UART on the wrong pin none of that lands, and the chip runs on its power-on
defaults: microstepping from the MS1/MS2 straps and **current from the VREF
potentiometer only**.

**`STEP` on A1 and `DIR` on A2 ⇒ they are swapped in effect.** The driver's STEP
input sees UART frames (edges only while the firmware transmits, i.e. at boot),
and its DIR input sees the step pulse train.

### Corrected Arduino ↔ TMC2209 wiring

```
TMC2209 EN    -> Arduino A4      (was A3)
TMC2209 UART  -> Arduino A1      (was A0)
TMC2209 STEP  -> Arduino A2      (was A1)
TMC2209 DIR   -> Arduino A3      (was A2)
TMC2209 GND   -> Arduino GND     (unchanged)
TMC2209 VDD   -> Arduino 5V      (unchanged)
Arduino A0    -> leave unconnected
```

## 3. The 10 pins on the pipette — this half of the diagram is correct

The OT-2 pipette's FC-10P connector, per the Jubilee tool doc's ribbon table and
the JST housing order `[Blue/4, Red/3, Green/1, Black/2]` (so coil 1 = ribbon 3+4,
coil 2 = ribbon 1+2):

| pipette pin | function | diagram | verdict |
|---|---|---|---|
| 1 | stepper coil B | → TMC `2B` | ✅ |
| 2 | stepper coil B | → TMC `2A` | ✅ |
| 3 | stepper coil A | → TMC `1B` | ✅ |
| 4 | stepper coil A | → TMC `1A` | ✅ |
| 5 | unused | — | ✅ |
| 6 | limit switch **return (GND)** | labelled `Limit switch GND` | ✅ |
| 7 | limit switch signal | → Arduino D9 | ✅ |
| 8, 9, 10 | unused | — | ✅ |

The coil grouping matters and it is right: 3+4 together and 1+2 together. Swapping
the two wires *within* a pair only reverses the direction of travel; **mixing the
pairs** (e.g. 1 with 3) makes the motor buzz and vibrate without turning. Since
there is no buzzing at all, the coil wiring is not the current fault.

### Which physical hole is pin 1 — the thing neither Ursa source states

Both Ursa-side sources give the *logical* pinout and neither says which end of
the connector is pin 1. The only source that does is science-jubilee's
[`OT2_Wiring_Diagram.pdf`](https://github.com/machineagency/science-jubilee/blob/main/tool_library/OT2_pipette/assembly_docs/OT2_Wiring_Diagram.pdf),
which is a **photograph of the pipette's own 10-pin header** with a coloured dot
on each populated hole. Read off it:

- the **top row of the header (9, 10) is empty**, and the two motor coils occupy
  the **bottom two rows** — `1|2` bottom, `3|4` above it;
- each coil is a **left-right pair within one row** (blue+red on `3|4`,
  black+green on `1|2`), matching the JST housing order `[Blue/4, Red/3,
  Green/1, Black/2]`;
- the limit-switch pair is **7 and 6 — diagonal**, one hole in each of two
  adjacent rows, not a same-row pair. Wiring it to 7+8 or 5+6 is the easy
  mistake.

If the populated rows are at the *other* end of the connector, the FC-10P is
crimped 180° out and every pin maps `n → 11 − n`: all four coil wires land on
unused pins 7–10 (silent motor, no buzzing) and the limit-switch pair lands on
pin 4 (a coil) and pin 5 (no connect). That case is testable without a
multimeter — see the D9 table below — and it is *excluded* on this machine,
because D9 has read LOW (loop closed) in three of the five wiring passes, which
a rotated connector could never produce.

Two-minute meter check, ribbon off the driver's screw terminals, everything
powered down: **blue–red** and **black–green** should each read a few to a few
tens of ohms; **blue–black** should read open, because the two coils of a
bipolar stepper are isolated. If both pairs read open, the fault is in the
crimps or the solder joints, not in the pinout.

### The limit-switch return, pin 6 → Arduino GND

`setupPipette()` does `pinMode(PIPETTE_LIMIT_PIN, INPUT_PULLUP)`, and D9 **HIGH
means "at the limit"** — so an open switch circuit reads *asserted*.

**This one pin explains both plunger symptoms.** `stepMotor()` gates the upward
direction on it:

```c
// Check for limit switch when moving UP (DIR_PIN is LOW for UP)
if (digitalRead(PIPETTE_LIMIT_PIN) == HIGH && digitalRead(DIR_PIN) == LOW)
{
    delay(DEBOUNCE_TIME);
    if (digitalRead(PIPETTE_LIMIT_PIN) == HIGH) { errorOccurred = true; break; }
}
```

and `homePipette()` checks it *before* its first step, so an asserted switch is
an instant "success" that runs only the 796-step back-off:

```c
digitalWrite(DIR_PIN, LOW);            // seek upward
while (!homingSuccessful && ...) {
    if (digitalRead(PIPETTE_LIMIT_PIN) == HIGH) { ... homingSuccessful = true; break; }
    ... step ...
    if (stepsCount > 50000) return false;      // ~26 s of seek
}
digitalWrite(DIR_PIN, HIGH);           // back off 796 steps @ 510 us = 0.406 s
```

| D9 reads | `HOME` | UP / retract moves | DOWN / forward moves |
|---|---|---|---|
| **HIGH (asserted)** | "success" in **0.52 s** — back-off only, no seek | aborted after 1 step + 100 ms debounce → **~0.11 s** | unaffected |
| **LOW (clear)** | full 50000-step budget, then `false` → **26.35 s** ERR | normal, scales with distance | unaffected |

Both constants are exact: 796 × 510 µs + `DEBOUNCE_TIME 100` = **0.506 s** vs.
0.52 s measured; 1 step + 100 ms = **~0.1 s** vs. 0.11 s measured.

Consequences for the wiring:

- **Pin 6 must reach Arduino GND**, which is what the diagram's
  `Limit switch GND` label means. Anywhere that loop is open — pin 6, pin 7, the
  switch itself, a crimp — D9 idles HIGH through the pull-up and you get the
  whole "HIGH" row above: a fake home *and* a plunger that refuses to retract.
- The contact must be **normally closed**: LOW (closed to GND) at rest, opening
  as the plunger reaches the limit. A normally-open contact gives the HIGH row.

Observed history on this machine, all four rewiring passes:

| date / pass | `HOME` | backward | ⇒ D9 |
|---|---|---|---|
| 2026-08-31, before any rewiring | 0.52 s | refused | HIGH |
| 2026-09-01 18:33, rewire #1 | 26.35 s ERR | moves | LOW |
| 2026-09-01 18:56, rewire #2 | 26.35 s ERR | moves | LOW |
| 2026-09-01 19:13, rewire #3 | 26.35 s ERR | moves | LOW |
| 2026-09-01 19:46, rewire #4 | 0.52 s | refused | HIGH |
| 2026-09-08, rewire #5 (Arduino pins corrected) | not measurable — hardware off the Pi | — | — |

Nothing else in the plunger's behaviour changed across those passes. Treat this
pin as the first thing to measure whenever the plunger misbehaves.

## 4. Fixing the UART pin opens a new way for the driver to be switched off

Added 2026-09-08, after the Arduino-side pins were corrected and the plunger
still did not move. This is a *software* failure mode, and it was not reachable
while UART was on the wrong pin.

`setupPipette()` → `setupMotor()` → `stepperDriver.setup(softSerial)` →
[`TMC2209::initialize()`](https://github.com/janelia-arduino/TMC2209/blob/main/src/TMC2209/TMC2209.cpp):

```cpp
void TMC2209::initialize(long serial_baud_rate, SerialAddress serial_address)
{
  serial_baud_rate_ = serial_baud_rate;
  setOperationModeToSerial(serial_address);   // i_scale_analog = 0  <- VREF pot out of circuit
                                              // pdn_disable = 1, mstep_reg_select = 1
  setRegistersToDefaults();
  clearDriveError();
  minimizeMotorCurrent();                     // IRUN / IHOLD -> minimum
  disable();                                  // CHOPCONF.toff = 0 -> output stage OFF
  disableAutomaticCurrentScaling();
  disableAutomaticGradientAdaptation();
}
```

`setupMotor()` then calls `setRunCurrent(50)`, `setHoldCurrent(30)`,
`setMicrostepsPerStep(16)`, `enableStealthChop()`, `enableCoolStep()` and
`enable()` to undo the last two lines.

**Every one of those is a UART write, and the link is write-only.**
`SoftwareSerial softSerial(RX_PIN, TX_PIN)` is `(A0, A1)`, and `Pipette.h` says of
A0: *"SoftwareSerial RX pin (not connected but required)"*. The TMC2209's UART is
single-wire half-duplex (PDN_UART); with only TX attached the Arduino can never
read the driver back, and `setupMotor()` never calls
`stepperDriver.isSetupAndCommunicating()`. Nothing anywhere verifies that a
single register write landed.

So the two wiring states behave very differently:

| UART wire on | what the driver does |
|---|---|
| **A0** (the RX pin — the Cubware diagram) | nothing is ever transmitted. Chip stays in **standalone mode**: VREF pot sets current, MS1/MS2 straps set 1/8 microstepping, `CHOPCONF.toff` at its power-on default of 3 → **output stage enabled** |
| **A1** (the TX pin — correct) | the first thing that lands is `i_scale_analog = 0`, **taking the current pot out of the circuit**, followed by `minimizeMotorCurrent()` and `disable()`. If any later write is dropped or garbled, the driver sits at **minimum current with its output stage off** — silent, no holding torque — while the Arduino happily bit-bangs STEP into it |

### Two ways this could have failed that are now ruled out

Measured against the pinned library on 2026-09-08 rather than assumed:

- **SoftwareSerial baud is not marginal.** The `setup(SoftwareSerial &)` overload
  defaults to **9600** (`TMC2209.h:67`), not the 115200 the `HardwareSerial`
  overloads use. `setupMotor()` passes no baud, so 9600 is what runs — comfortable
  on a 16 MHz ATmega328P.
- **`enable()` does not write another zero.** `toff_` is initialised to
  `TOFF_DEFAULT = 3` (`TMC2209.h:508-510`), so `enable()` restores a live chopper
  config.

So the UART path only strands the driver if the register writes **partially**
land — `setOperationModeToSerial` + `minimizeMotorCurrent` + `disable` arriving
while the later `setRunCurrent`/`enable` do not. That is a narrower failure than
"UART is misrouted", and it needs a marginal connection rather than a wrong one.
Worth keeping on the list, no longer at the top of it.

### The bisect: pull the UART wire off A1

Nothing else changes. With the wire off, `setup()`'s writes go nowhere, the chip
never enters serial mode, and it runs on its power-on defaults with the pot back
in charge of current.

- **Plunger moves** → the fault is in the UART configuration path. (Distances will
  come out 2× — standalone MS1/MS2 default to 1/8, not the 1/16 the firmware
  assumes; see §6.)
- **Plunger still silent** → it is power, current, or the coil circuit. §5 and the
  meter check in §3.

Either way, turn the VREF pot up before running the test.

If you would rather instrument than unplug: tie A0 to the same PDN_UART line
through a 1 kΩ resistor — that is how the janelia library's single-wire mode is
meant to be wired — and then `isSetupAndCommunicating()` becomes meaningful and
can be checked after `setup()`.

### ⚠️ Turn the run current down before it works

`RUN_CURRENT_PERCENT 50` maps to `IRUN = 15` of 31, with `CHOPPER_CONFIG_DEFAULT
= 0x10000053` leaving `vsense = 0` (the high-current range) and the firmware never
calling `enableVSense()`. On a breakout Adafruit rates to 2 A that is on the order
of **0.9 A RMS / 1.2 A peak**.

The same science-jubilee source this harness comes from specifies **350 mA peak
for a gen1 OT-2 pipette motor and 500 mA for a gen2** (`M906 V350` / `M906 V500`).
So the firmware asks for roughly 2–3× the motor's rating — and *that only starts
mattering once the UART wire works*, because until then the pot was in charge.
Drop `RUN_CURRENT_PERCENT` to ~20 and `HOLD_CURRENT_PERCENT` to ~10 before the
first successful move, and fit the Adafruit `1515` heat sink to the driver
(Cubware's setup page has a section on it).

## 5. Two more things on that page

**"120V/2A Power Supply" is a typo for 12 V.** The Adafruit 6121 breakout takes
5–29 VDC on the motor terminal. Do not connect mains.

**12 V at 2 A into the driver's VM terminal is the right supply, and 2 A is a
ceiling rather than a setting.** A stepper driver is a current source: the coil
current is whatever IRUN/VREF asks for, and the supply's amp rating only has to
be at least that. It is the driver's *current setting* that needs to come down to
the motor's 350–500 mA, not the supply. Two things to keep in mind: the supply
must land on the driver's VM/GND screw terminal, not on VDD (VDD is logic only,
and the board enumerates and acks every command happily with VM absent — silently);
and 12 V into a 350 mA motor is a lot of headroom, so fit the heat sink and keep
the current setting low.

**The motor supply is separate from VDD.** The Arduino's 5 V on `VDD` powers the
driver's logic only. With no voltage on the `+`/`-` terminal the board still
accepts STEP/DIR and acknowledges everything, with zero coil current and total
silence — indistinguishable at the serial port from a healthy run.

## 6. What the 2026-09-08 measurements narrowed it to

Both readings came from `cubos/tools/pipette_driver_probe.py`, which drives the
firmware's `CMD_MOVE_RELATIVE` (code 16) in raw steps. That command reports an
aborted move **explicitly** (`ERR:{"error":"Failed to move relative"}`) instead of
leaving it to be inferred from a round-trip time, and its DOWN direction is not
gated by the limit switch at all.

```
limit switch   ASSERTED (D9 HIGH, loop OPEN)   dt=0.11s  ERR:{"error":"Failed to move relative"}
motor          DOWN 1.0 mm at 400 steps/s      dt=4.04s  expected 4.00s  OK
```

### The Arduino is not the problem

1592 steps at exactly the commanded rate, deliberately slow so the motor makes
its most torque and most noise. Everything upstream of the STEP pin works. The
fault is between the Arduino header and the motor windings.

### The one hypothesis that explains both symptoms at once

D9 reading HIGH means the **switch loop is open**, and total silence with no
buzzing means **no coil current** (a swapped coil *pair* buzzes and vibrates;
open coils are silent). Both the switch loop and both coils arrive on the same
FC-10P connector at the pipette. A connector that is not fully seated, or a bad
crimp row, opens all of them together.

The switch reading has also flipped between passes — asserted before 2026-09-01,
clear for three passes on 2026-09-01, asserted again since — while the Arduino
end was being rewired. An intermittent contact behaves exactly like that; a wrong
pinout does not.

So the meter check in §3 is now the first thing to do, not the last:

```
ribbon unplugged from the driver terminals, everything powered down

blue–red     a few to a few tens of ohms      coil A
black–green  a few to a few tens of ohms      coil B
blue–black   open                             the coils are isolated from each other
pin 6–pin 7  CLOSED at rest                   the limit switch, normally-closed
```

Both coil pairs open ⇒ the connector or the crimps, not the pinout. Pin 6–7 open
at rest ⇒ the same loop, or a normally-*open* switch, which the firmware cannot
use.

### Holding torque is the test that ignores the mechanical stop

`--motor-test` cannot tell "no coil current" from "the plunger is already against
its stop" — and the plunger *is* being ratcheted outward, see below. Holding
torque can: with the driver idle and powered, grab the plunger and try to turn or
push it. Energized coils resist noticeably (`HOLD_CURRENT_PERCENT 30`). No
resistance at all means no coil current, whatever position it is in.

### ⚠️ While the switch reads asserted, the plunger only travels one way

Every upward command is refused by the gate in `stepMotor()`, `HOME` only zeroes
the counter, and there is no other retract path in the command set. So each run
that reaches `aspirate` drives the plunger further out and nothing brings it
back. Fixing the switch loop is what restores the ability to retract at all — it
is not only a homing problem.

### `ASPIRATE`'s reported positions, explained

`aspirate()` clamps to `MIN_VOLUME 5.0`, moves **down to `PRIME_POSITION 36.0`
first**, then up to `36.0 - volume * UL_TO_MM`. The second leg is upward, so the
gate applies:

- switch clear → both legs run → reports 35.45
- switch asserted → second leg refused → reports 36.00

Every value seen in the logs is one of those two. It also means aspirate is never
a small move: it drives to 36.0 whatever volume is asked for. (`dispense()`
ignores its volume argument entirely and moves to `BLOWOUT_POSITION 44.0`.)

### Where 0.673 s/mm comes from

`stepMotor()` sets `stepDelay = 1000000 / velocity` clamped to [100, 10000] µs.
At `MOVEMENT_VELOCITY = 2500` steps/s that is 400 µs, plus ~23 µs of
`digitalWrite`/`digitalRead`/loop overhead → ~423 µs per step, and at
`STEPS_PER_MM 1592` that is **0.673 s/mm**. Arithmetic, not a fit — which is why
a round trip that fails to scale with distance is conclusive.

## 7. Consequences that outlive the wiring fix

**Microstepping is almost certainly 1/8, not the 1/16 the firmware assumes.**
`setMicrostepsPerStep(16)` is a UART write, so with UART unconfigured the chip
uses its MS1/MS2 straps, which default to 1/8. The firmware's own numbers admit
it: `STEPS_PER_MM 1592.0`, but the homing back-off says
`int backOffSteps = 796; // this is equal to 1mm` — exactly half. Same factor in
`if (stepsCount > 50000) // About 62mm of travel`: 50000 steps is 31 mm at 1592
steps/mm and 62 mm at 796. **Expect commanded millimetres to come out 2× on the
plunger** until either the UART wire is fixed or MS1/MS2 are strapped for 1/16.
Check it with a ruler on the first successful move.

**Volumes are double-converted, then clamped.** CubOS computes
`mm_travel = volume_ul * mm_to_ul` and sends that as the `ASPIRATE` argument, but
the firmware's `aspirate(float volume, ...)` takes **microlitres** and does its own
`volume * UL_TO_MM` internally. It also clamps to `MIN_VOLUME 5.0` /
`MAX_VOLUME 300.0` first. So a protocol asking for 20 µL sends `ASPIRATE 0.5`, the
firmware clamps 0.5 → 5 µL, and the plunger targets
`PRIME_POSITION 36.0 − 5×0.1098 = 35.45` — the exact value in every trace. To pass
real microlitres through, `mm_to_ul` would have to be **1.0**.

**`aspirate` always primes first.** `aspirate()` runs `moveTo(PRIME_POSITION)`
before anything else, so the plunger travels to 36.0 mm regardless of the
requested volume. `dispense()` ignores its volume argument entirely and just moves
to `BLOWOUT_POSITION 44.0`.

**The firmware is built for a P300.** `MAX_VOLUME 300.0`, `UL_TO_MM 0.1098`,
`PRIME 36.0`, `BLOWOUT 44.0`, `DROP_TIP 55.0`, and a `P300.json` beside it. That is
why `STATUS` reports `max_vol: 300.00` with a p20 on the head. CubOS's
`p20_single_gen2` entry in `instruments/pipette/models.py` is all
`# placeholder` values and does not correspond to this firmware at all.

**Timing at the serial port cannot see the motor.** `stepMotor()` bit-bangs STEP
and counts loop iterations; there is no encoder, no current sense, no feedback.
A move that takes the expected `0.673 s/mm` proves the *Arduino* stepped and
nothing more. (0.673 s/mm is itself just the firmware's arithmetic:
`MOVEMENT_VELOCITY 2500` → 400 µs/step, × `STEPS_PER_MM 1592` ≈ 0.67 s/mm.)
Likewise `HOME` failing after 26.35 s is the 50000-step budget in
`homePipette()`, not the 60 s timeout.

---

## 8. The science-jubilee prior art

`machineagency/science-jubilee` is the upstream of this whole pipette harness —
`BU-KABlab/PANDA_Arduino` vendors a copy of its tool doc at `src/pipette_tool.md`,
and Ursa's `Cubware/documentation/opentrons-pipette-setup.md` delegates to PANDA.
It drives the same OT-2 pipette from a **Duet 3 / RepRapFirmware** V axis instead of
an Arduino + TMC2209, so it is an independent implementation of the same mechanism —
which makes it usable as a cross-check on every constant PANDA carries.

Sources (MIT licensed):

| what | where |
| --- | --- |
| Duet `config.g` recipe | [`tool_library/OT2_pipette/duet_configs/OT2_Pipette_Configuration.md`](https://github.com/machineagency/science-jubilee/blob/main/tool_library/OT2_pipette/duet_configs/OT2_Pipette_Configuration.md) |
| Python driver | [`src/science_jubilee/tools/Pipette.py`](https://github.com/machineagency/science-jubilee/blob/main/src/science_jubilee/tools/Pipette.py) |
| Per-model constants | [`src/science_jubilee/tools/configs/P20_config.json`](https://github.com/machineagency/science-jubilee/blob/main/src/science_jubilee/tools/configs/P20_config.json) (also P300, P1000) |
| Header photo | [`tool_library/OT2_pipette/assembly_docs/OT2_Wiring_Diagram.pdf`](https://github.com/machineagency/science-jubilee/blob/main/tool_library/OT2_pipette/assembly_docs/OT2_Wiring_Diagram.pdf) |
| Tip-sensor holders | `tool_library/OT2_pipette/designs/3D_only/PipetteTool_Holder_{Mechanical,Dust-Proof}_Limit_Switch.stl` |

### 8.1 The two systems agree on the pipette, and that validates PANDA's numbers

RRF sets steps per axis unit with `M92`; the doc gives **48 (Gen1) / 200 (Gen2)** at
`M350 V16 I1`. PANDA uses `STEPS_PER_MM 1592.0`, also at 16x. Those are not the same
unit — the ratio is `1592 / 200 = 7.96`.

Which one is a millimetre falls out of the motor arithmetic. At 16x on a 200-step
motor:

```
PANDA  1592 / 16 =  99.5 full steps per unit  ->  2.01 mm of lead per revolution
SJ      200 / 16 =  12.5 full steps per unit  ->  16.0 mm of lead per revolution
```

2 mm is an ordinary leadscrew lead; 16 mm is not. **PANDA's "mm" are real
millimetres and science-jubilee's V units are ~7.96 mm each** — their `M92 V200`
is steps-per-V-unit, and nothing in their stack ever needs it to be a millimetre
because every position and volume constant is calibrated in those same units.

That in turn makes PANDA's plunger constants physically sensible: `PRIME 36.0`,
`BLOWOUT 44.0`, `DROP_TIP 55.0` mm, with `homePipette()`'s 50000-step budget being
31.4 mm — i.e. a ~55 mm plunger stroke, which is what an OT-2 pipette has.

The volume calibration cross-checks too. Converted to steps per microlitre — a
property of the piston alone, independent of how either project mounts the tool:

```
science-jubilee P300:  0.91   units/uL x  200 steps/unit = 182.0 steps/uL
PANDA           P300:  0.1098 mm/uL    x 1592 steps/mm   = 174.8 steps/uL
                                                    agree to within 4%
```

Two independent projects, two different controllers, same answer. **PANDA's
`UL_TO_MM 0.1098` is a real P300 calibration, not a placeholder.**

### 8.2 ...which is exactly why the P20 numbers are not trustworthy on either side

Upstream ships a `P20_config.json` for a "P20 Gen 2". Running the same consistency
check on all three of their configs — full-scale volume against the axis travel that
`zero_position` makes available:

| model | `zero_position` | `mm_to_ul` | full-scale stroke | % of available travel |
| --- | ---: | ---: | ---: | ---: |
| P1000 | 310 | 0.31 | 310.0 | **100%** |
| P300 | 310 | 0.91 | 273.0 | **88%** |
| **P20** | 250 | **0.8531** | **17.1** | **6.8%** |

P1000's value is exactly `zero_position / max_volume`; P300's sits 12% under it, which
is what a gravimetric trim looks like. P20's is neither — a P20 whose full 20 µL used
under 7% of the plunger travel would be a pipette that is 93% dead band. `0.8531` is
within 6% of the P300's `0.91`, which is what a copied line looks like, not a
calibration.

Self-consistent values, for anyone picking this up:

```
science-jubilee units:   mm_to_ul ~ 250 / 20 = 12.5   (vs the shipped 0.8531)
PANDA millimetres:       UL_TO_MM ~  36 / 20 =  1.8   (vs P300's 0.1098)
CubOS p20_single_gen2:   mm_to_ul   0.025 is ~72x too small
```

All three are estimates from "full volume uses the full stroke" and need a
gravimetric calibration before any number is a microlitre. The point is only that
the shipped values are wrong by one to two orders of magnitude, not by a few percent.

Also from that table: **`MIN_VOLUME`/`MAX_VOLUME` in the firmware are P300 values**
(`5.0` / `300.0`); upstream's P20 entry is `min_volume: 1, max_volume: 20`. The
firmware's `constrain(volume, MIN_VOLUME, MAX_VOLUME)` is why `ASPIRATE 0.5` has
always landed at 35.45 — 0.5 clamps up to 5, and `36.0 - 5 x 0.1098 = 35.451`.

### 8.3 Gen1 and Gen2 are 4.17x apart, and PANDA hardcodes one number

`M92 V48` vs `M92 V200` — the two generations do not share a drive ratio. `M906`
differs too: **350 mA peak for Gen1, 500 mA for Gen2**. PANDA has a single
`STEPS_PER_MM` and a single current, so the generation printed on the pipette body
(the diagram's own pipette reads `P300 GEN2`) has to be checked before any of these
constants mean anything.

### 8.4 Run current: PANDA asks for roughly 2.5x the motor's rating

`M906 V500` is the Gen2 spec. `RUN_CURRENT_PERCENT 50` in the janelia library maps
to `IRUN ~ 15/31`, and with `CHOPPER_CONFIG_DEFAULT = 0x10000053` leaving `vsense = 0`
(and `enableVSense()` never called):

```
I_rms = ((CS+1)/32) x (0.325 / (R_sense + 0.02)) / sqrt(2)
CS=15, R_sense=0.11:  884 mA rms = 1.25 A peak     vs. the 500 mA peak spec
```

Working backwards for the spec values (same assumptions):

| target | CS | `RUN_CURRENT_PERCENT` |
| --- | ---: | ---: |
| 350 mA peak (Gen1) | ~4 | **~11** |
| 500 mA peak (Gen2) | ~5 | **~17** |

Scale if the Adafruit 6121's sense resistor is not 0.11 Ω, and prefer
`enableVSense()` (0.18 V full scale) for usable resolution down here. Fit the
Adafruit 1515 heat sink either way.

### 8.5 The Duet can see why a driver isn't driving. This port cannot

RRF reports `open_load_a/b`, `short_to_ground_a/b` and over-temperature per driver
through `M122`. The same flags are on the TMC2209 and the janelia library exposes
them — `getStatus()` returns a struct with `open_load_a`, `open_load_b`,
`short_to_ground_a`, `short_to_ground_b`, `over_temperature_shutdown`, plus
`isSetupAndCommunicating()`.

**None of it is reachable here, because PANDA wires the UART one-way.**
`SoftwareSerial softSerial(RX_PIN, TX_PIN)` with `RX_PIN 14` documented as
"not connected but required". So the driver cannot report a fault, and
`setupMotor()` never asks whether a single register write landed.

The library's README gives the fix directly: *"the simplest way to connect the
single TMC2209 serial signal to both the microcontroller TX pin and RX pin is to use
a 1k resistor between the TX pin and the RX pin to separate them."* One resistor
between **A0 and A1** turns the link bidirectional.

That is worth doing before any more wiring passes. `open_load_a` / `open_load_b`
answer "are the coils actually connected to the driver" without a meter, and
`over_temperature_shutdown` and `short_to_ground_*` are both latching states that
present as a silent motor and are invisible today.

### 8.6 The header photo, and the check it supports

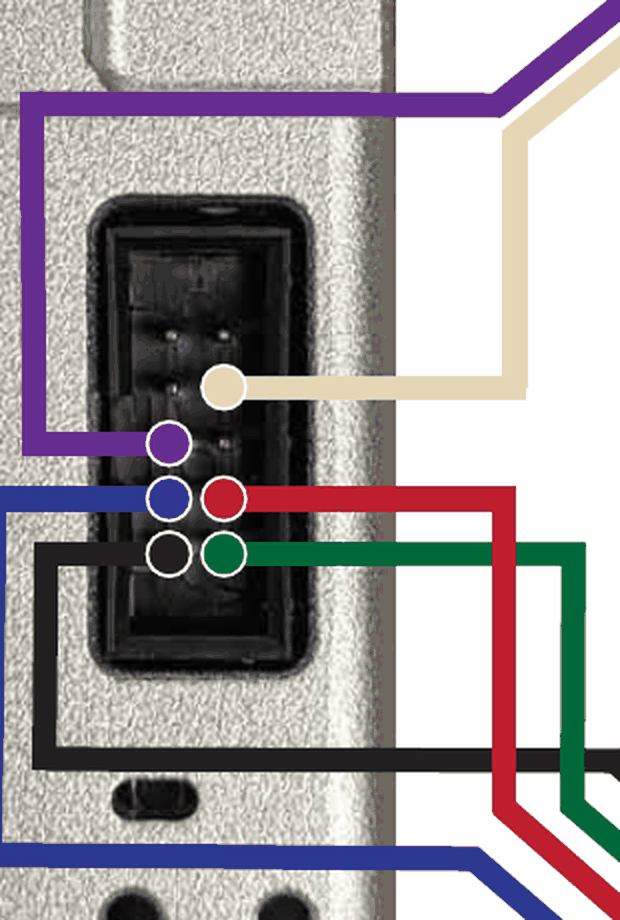
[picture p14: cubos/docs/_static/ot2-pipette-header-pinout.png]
OT-2 pipette 10-pin header


*Crop of `OT2_Wiring_Diagram.pdf`, machineagency/science-jubilee, MIT. Coloured dots
mark the populated holes; tan and purple are the limit switch, blue/red/green/black
are the motor.*

This is the only source anywhere that shows which physical hole is which. Reading it
against the ribbon table (`1` Green, `2` Black, `3` Red, `4` Blue on the motor;
`6` Black, `7` Red on the switch; `5`, `8`, `9`, `10` unused) resolves the numbering
completely and self-consistently:

| row, from the pipette-tip end | left column | right column |
| --- | --- | --- |
| 1 (closest to the tip) | **2** black, coil B | **1** green, coil B |
| 2 | **4** blue, coil A | **3** red, coil A |
| 3 | **6** black, switch return | 5 — empty |
| 4 | 8 — empty | **7** red, switch signal |
| 5 (farthest from the tip) | 10 — empty | 9 — empty |

Odd pins in one column, even in the other, pin 1 at the tip end. The
viewing-independent form, which is what to check by eye:

> **The two fully-populated rows are the two nearest the pipette tip. The four empty
> holes are the far row plus one hole in each of the two rows next to it.**

### 8.7 What a 180-degree connector flip would actually look like

Worth writing down precisely, because the mapping is not intuitive. Under a flipped
FC-10P, conductor `c` lands on header pin `11 - c`:

```
conductor 1 (green, coil B) -> header pin 10   unused inside the pipette
conductor 2 (black, coil B) -> header pin  9   unused
conductor 3 (red,   coil A) -> header pin  8   unused
conductor 4 (blue,  coil A) -> header pin  7   the switch SIGNAL
conductor 6 (switch return) -> header pin  5   unused
conductor 7 (switch signal) -> header pin  4   one end of coil A
```

Both coils end up with at least one terminal on an unused pin, so **no coil current
and no buzzing**. And D9 lands on coil A, whose other end is header pin 3, fed by
conductor 8 — which is unconnected at the machine end. So D9 dead-ends and floats,
and the pullup makes it **read asserted, permanently**.

That "permanently" is the discriminator. A flip cannot produce the 2026-09-01
sessions where `HOME` ran its full 26.35 s budget and retractions worked — those
require D9 LOW. So a flip only explains the record if the FC-10P has been
re-terminated since, which it has not. The **machine-end junction**, where four
motor wires and two switch wires are soldered onto ten ribbon conductors, remains
the better suspect: it is the one place a persistent coil fault and a
rework-sensitive switch fault can coexist, and it is the least keyed, least
documented joint in the chain.

### 8.8 Two things upstream does that would close open items here

**Homing has a direction check with a named failure mode.** `homev.g` is a coarse
seek, a back-off, then a slow re-seek:

```gcode
G91
G1 V-200 F800 H1   ; coarse seek toward the endstop
G1 V1    F600      ; back off
G1 V-10  F600 H1   ; slow re-seek
G90
G1 V0.5  F600
```

and the doc says to watch the drive shaft the first time: it must move *toward* the
endstop, and **"if you notice the pipette tip ejector starts to engage"** the
direction is inverted — stop it by pressing the endstop by hand (twice, once per
seek) and flip `M569 S`. On this machine the equivalent knob is `DIR_PIN` polarity in
`homePipette()`, which currently seeks with DIR LOW. The endstop convention matches
PANDA's exactly: `M574 V1 S1 P"^pin"` enables the pullup and treats HIGH as
triggered, so both projects expect a **normally-closed** switch to ground.

**Tip pickup is sensed, not a friction press.** Upstream fits a *second*, external
limit switch that trips when the nozzle seats into a tip, wires it as the machine's
Z endstop, and picks up tips with `G1 ... H4` — move until the endstop trips, no
error:

```python
self._machine.move_to(z=z, s=800, param="H4")
```

That is the open item on this branch: `pick_up_tip` here is an unsensed press, so
`pickup_z` cannot be verified in software and a missed tip is silent. Printable
holders for the switch are in `designs/3D_only/`
(`PipetteTool_Holder_Mechanical_Limit_Switch.stl`, and a dust-proof variant), plus
`endstop_attachment.STL` in the laser-cut set.

### 8.9 The command semantics are the same, which is reassuring

`Pipette.py` orders the plunger `aspirate < zero_position < blowout_position <
drop_tip_position`, with `_aspirate` moving negative from `prime()` and `blowout()`
returning to prime afterwards. PANDA is the same scheme (`ZERO 0 < PRIME 36 <
BLOWOUT 44 < DROP_TIP 55`, `aspirate()` subtracting from `PRIME_POSITION`), so the
port is faithful. Two divergences worth knowing:

- PANDA's `dispense(float /*volume*/, ...)` **ignores its volume argument** and moves
  to `BLOWOUT_POSITION`. Upstream's `_dispense` is a true relative move of
  `vol * mm_to_ul`. PANDA does have relative equivalents — `aspirateRelative`,
  `dispenseRelative`, `plungerMoveRelative` — which CubOS never calls.
- CubOS's `drop_tip_position` for the p300 is `60.0`; the firmware's is `55.0`.
  The firmware sets `maxPosition = DROP_TIP_POSITION` and `moveTo()` runs
  `constrain(positionMM, minPosition, maxPosition)`, so a commanded `60.0` is
  silently clamped to `55.0`. It lands on the real eject stop, but the CubOS
  constant is fiction.
- CubOS's `p300_single_gen2` carries `max_volume=200.0`. A P300 is 300 µL, and the
  firmware agrees (`MAX_VOLUME 300.0`). Upstream's P300 config also says 300.

### 8.10 Order of operations, given all of the above

1. **The 1k resistor from A0 to A1**, and read `getStatus()`. `open_load_a/b` answers
   the coil question without a meter, and `over_temperature_shutdown` /
   `short_to_ground_*` are latching failures that look exactly like this one.
2. **Check the generation** printed on the pipette body. Gen1 and Gen2 differ 4.17x
   in steps per unit and 350 vs 500 mA in current.
3. **Drop `RUN_CURRENT_PERCENT` to ~17** (Gen2) or ~11 (Gen1) before the first
   successful move, and fit the heat sink.
4. **Then** the volume constants: `MAX_VOLUME`/`MIN_VOLUME` for a p20 (20 / 1),
   `UL_TO_MM` from a gravimetric calibration (~1.8 mm/µL as a starting estimate),
   and `mm_to_ul: 1.0` on the CubOS side so `volume_ul` passes through as
   microlitres instead of being converted twice.
5. **The sensed tip pickup** (§8.8) whenever the tip-seating question comes back.

---

## 9. 2026-09-15: the resistor went in, the firmware was taught to listen, and the driver said nothing

Ben fitted a **10 kΩ** bridge between A0 (`RX_PIN`) and A1 (`TX_PIN`) — the
single-wire UART arrangement §8.10 step 1 asked for. 10 kΩ rather than 1 kΩ is
electrically fine: the driver has to pull the line low against the Arduino's
idle-high push-pull output, which is 0.5 mA at 5 V, and at 9600 baud
(104 µs/bit) the RC of 10 kΩ against tens of picofarads is not close to
mattering.

### 9.1 The resistor alone changes nothing, and campaign 26 proved it

The trio ran that day with the bridge in place and produced a plunger trace
**byte-for-byte identical** to campaigns 77 and 83: `HOME` back in 0.520 s
(back-off only), the two downward commands stepping, all four upward commands
refused in ~0.107 s.

That is expected rather than disappointing. `setupMotor()` only ever *writes*
TMC2209 registers and checks none of them, and no command in `Interface.cpp`
exposed driver state — so the readback path the bridge creates had nothing
asking it a question. **The bridge is necessary and was not sufficient.**

### 9.2 So the firmware was taught to ask

`CMD_PIPETTE_DRIVER_STATUS = 29`, added in the same reflash as the p20
constants (see [`../firmware/README.md`](../firmware/README.md)), returns
`comm` / `flags` / `current_scaling`. Five consecutive reads, immediately after
the flash:

```
OK:{"msg":"Driver status","v":[0.00,0.00,-1.00]}
```

`comm = 0` is unambiguous — the library's `isCommunicating()` is
`getVersion() == VERSION`, so 0 means the driver did not return a valid version
byte. Not "replied but unconfigured"; **no reply at all**.

### 9.3 What that rules in and out

Every register write `setupMotor()` makes has therefore never landed, on any
run since this rig was built. The driver has been running on power-on defaults
throughout. Two consequences, pulling in opposite directions:

* **`setOperationModeToSerial()` never landed either**, so `i_scale_analog` is
  still 1 and the **VREF potentiometer is in circuit**. The §4 worry — that
  correcting the UART pin would strand the driver at minimum current with its
  output stage off — is therefore *not* what is happening. That hypothesis is
  now dead.
* `setMicrostepsPerStep(16)` never landed, so MS1/MS2 straps decide. Their
  default is 1/8, which is half of what `STEPS_PER_MM 1592.0` assumes — the
  same 2× the firmware already contradicts itself about in
  `int backOffSteps = 796; // this is equal to 1mm`. **Check the first
  successful move against a ruler.**

### 9.4 The discriminator, and it takes two minutes

With the driver idle and powered, try to turn the plunger by hand.

| holding torque | reading | next |
| --- | --- | --- |
| **none** | no coil current at all | VM at the driver's screw terminal (12 V; VDD from the Arduino is logic only and the board enumerates happily without VM), then the VREF pot, then coil continuity |
| **present** | the driver is powered and energised, so `comm = 0` is the UART path alone | confirm PDN_UART really lands on **A1**, and the bridge |

The new `flags` word reports `open_load_a`/`open_load_b` directly, which would
settle the coil question without a meter — but those bits come back *in a
reply*, so they only mean anything once `comm` is non-zero. Fix `comm` first.

### 9.5 What is now closed

| §8.10 step | state |
| --- | --- |
| 1. bridge + `getStatus()` | **done** — bridge fitted, firmware reads it, answer is `comm = 0` |
| 2. generation | **done** — `P20 GEN2`, off the body in `../results/pi5_des4_provision_20260914/pipette_label_p20_gen2.jpg` |
| 3. `RUN_CURRENT_PERCENT` → 17 | **done** (and `HOLD_CURRENT_PERCENT` → 10, which is forced: the library maps hold independently of run, so 30 against 17 would draw more standing still than moving). Heat sink still to fit. |
| 4. volume constants | **done** — `MAX_VOLUME` 20, `MIN_VOLUME` 1, `UL_TO_MM` 1.8 in firmware; `mm_to_ul: 1.0` in CubOS. `UL_TO_MM` is a starting estimate awaiting a gravimetric calibration. |
| 5. sensed tip pickup | still open |

One more thing settled in passing: the P300-shaped `ASPIRATE` behaviour is
gone. `MIN_VOLUME` 5.0 was why `ASPIRATE 0.5` always landed at 35.45
(0.5 clamped up to 5, then `36.0 − 5 × 0.1098`). With the p20 constants a
commanded 20 µL is `ASPIRATE 20.0` → 36.0 mm → plunger at 0.0, full scale.

---

## 10. 2026-09-17: Ursa's review, two retractions, and the P20 GEN2 numbers

Alex Carlson reviewed sections 1–9 against Cubware, `PANDA_Arduino`, the
janelia TMC2209 source, CubOS `origin/main`, Opentrons `shared-data`, the
Opentrons OT-2 open-hardware schematics and the Adafruit 6121 schematic
([byu-vcl issue #133, 2026-09-17][ursa-review]). Two of the conclusions in
this document do not survive that review. Both are corrected in place below
rather than edited out, because the reasoning that produced them is the
reasoning to avoid repeating.

[ursa-review]: https://github.com/vertical-cloud-lab/byu-vcl/issues/133#issuecomment-5719634392

### 10.1 🔴 RETRACTED: `comm = 0` was never evidence of anything

Sections 9.2–9.5 treated `CMD_PIPETTE_DRIVER_STATUS` returning `comm = 0` as
proof that *none of `setupMotor()`'s register writes had ever landed*, and
built on that to retract the section-4 hypothesis. **That inference is
unsound.** A read over `SoftwareSerial` on an AVR cannot succeed with this
library at all, whatever the wiring:

- AVR `SoftwareSerial::write()` runs `cli()` for the duration of each
  transmitted byte, so the Arduino never receives its own transmission back.
  The janelia README says software serial "should only be used for
  unidirectional communication" for exactly this reason.
- `TMC2209::sendDatagramBidirectional()` waits up to
  `ECHO_DELAY_MAX_MICROSECONDS` (4000) for `datagram_size` bytes and then
  **discards them as echo**. With no echo, the bytes that arrive in that
  window are the driver's 8-byte reply: the first 4 are thrown away,
  `readReply()` then waits for 8 more, times out, retries 5x, and
  `isCommunicating()` — which is `getVersion() == 0x21` — reports false.

So `comm = 0` is the *structural* outcome on an Uno. It says nothing about
whether the driver is powered, configured, or wired. **Writes need no echo
and may have been landing the whole time**, which means
`RUN_CURRENT_PERCENT`, `setMicrostepsPerStep(16)` and `enable()` may all
have been in effect, and the section-4 hypothesis is *not* excluded after
all.

The lesson worth keeping: a diagnostic that cannot return a positive result
is not a diagnostic. `getDriverDiagnostics()` was added in good faith and
then trusted without first asking whether its success path was reachable.

Two changes are needed before that reading means anything:

1. **`tmc2209-softwareserial-read.patch`** (in `cubos/patches/`) — skips the
   echo wait-and-discard block when `software_serial_ptr_` is set. Written and
   built; see §10.4 for why it is not yet on the board.
2. **The bridge resistor has to move to the TX side.** Per TMC2209 datasheet
   §4.3 fig 4.1 and the janelia "coupled" wiring diagram: `A1 -> 1k -> node`,
   with `A0` and `PDN_UART` connected *directly* to the node. With `A1` wired
   straight to `PDN_UART` and the resistor only on the `A0` leg, the
   Arduino's push-pull TX shorts out the driver's reply. **This is a bench
   change, and the library patch alone will not produce a valid read without
   it.**

### 10.2 🔴 CORRECTED: the sense resistor is 0.05 Ω, not 0.11 Ω

§8.4 assumed 0.11 Ω "the common value" and scaled every current figure from
it. Ursa read the actual value off the Adafruit 6121 schematic: `R1`, `R2` =
**0.05 Ω / 0.25 W**. Recomputing, with `vsense = 0` (`enableVSense()` is
never called) and the library's `CS = map(percent, 0, 100, 0, 31)`:

```
I_rms = ((CS+1)/32) * (0.325 / (0.05 + 0.02)) / sqrt(2) = ((CS+1)/32) * 3.283 A
```

| `RUN_CURRENT_PERCENT` | CS | I_rms | I_peak | |
|---|---|---|---|---|
| 50 | 15 | 1.64 A | **2.32 A** | BU original — over the board's 2 A rating |
| 17 | 5 | 0.62 A | 0.87 A | VCL 2026-09-15 |
| **20** | **6** | **0.72 A** | **1.02 A** | **matches Opentrons `plungerCurrent` 1.0 A** |
| 5 | 1 | 0.21 A | 0.29 A | matches Opentrons `idleCurrent` 0.3 A |

So the 50 that shipped from BU was worse than §8.4 said — over the
*breakout's* rating, not merely over the motor's. And the 500 mA peak figure
§8.4 used as the target is **science-jubilee's Duet choice, not Opentrons'**.
Opentrons' own `p20_single_v2.x` definition runs the plunger at
`plungerCurrent: 1.0 A` and idles at `idleCurrent: 0.3 A`. Those are the
numbers to match for this pipette, and 17 was conservative rather than
correct.

### 10.3 Other facts from the 6121 schematic worth recording

- Header order: `1 VDD, 2 GND, 3 DIR, 4 STEP, 5 MS1, 6 MS2, 7 DIAG, 8 INDEX,
  9 UART, 10 EN`.
- **`EN` has a 20 kΩ pull-down**, so the driver is enabled even with the `EN`
  wire absent. Moving `EN` from A3 to A4 was still right, but §3's claim that
  a mis-landed `EN` would leave the driver dead does not hold for this board.
- `MS1`/`MS2` have no board pulls and the chip pulls them down internally →
  **1/8 microstepping and UART address 0**. Address 0 matches the library
  default, so addressing was never the problem. 1/8 does mean a commanded
  millimetre travels two, if the microstep write never lands — the open
  question of §7.
- **The VREF pot is fed from the chip's own `5VOUT` through 33 kΩ, and
  `5VOUT` is generated from `VM` only.** `VCCIO` does not power the analogue
  side.

That last point is the important one, and it is why **`VM` remains the first
thing to measure**. With `VM` absent: `5VOUT` is dead, so VREF is zero, so
coil current is zero; the driver cannot reply on UART; and every `STEP`/`DIR`
command is still accepted and acked by the Arduino. One cause, every symptom
— including Ben's 2026-09-17 bench result that **the plunger moves freely by
hand with the driver powered and idle**, i.e. no holding torque, i.e. no coil
current.
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

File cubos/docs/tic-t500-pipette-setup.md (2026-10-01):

# Driving the P20 GEN2 with a Pololu Tic T500

Written 2026-09-29, as a candidate replacement for the condemned Adafruit 6121
TMC2209 board (§22 of [`opentrons-pipette-wiring.md`](./opentrons-pipette-wiring.md)).
**Status, 2026-09-30: the pipette works on the Tic.** With `STEPS_PER_MM 796`
flashed, the trio ran 12/12 (campaign 68), and Ben saw it aspirate, dispense and
drop the tip ([record](../results/pipette_test_20260930b/README.md)). The ruler
or balance check of the 796 scale is still open.
**Earlier, 2026-09-29 18:10: the plunger moves.** Bring-up steps 1, 3 and 5 are
done. Driven through the Arduino, the plunger went up about 28.7 mm and opened
the limit switch. It went down and closed it again, then reopened it after the
same 2 mm at every rate from 200 to 2,500 microsteps/s. The firmware's own
`HOME` then succeeded in 1.36 s. The polarity is right: direction 0 goes toward
the switch, so no `A1`↔`A2` swap is needed. What remains is steps 6 and 7:
confirm 796 microsteps/mm, then flash it. **Don't connect CubOS before step 7.**
Records: [switch test](../results/pipette_switch_search_20260929/README.md),
[first moves](../results/tic_t500_first_moves_20260929/README.md),
[settings](../results/tic_t500_settings_20260929/README.md). The Tic was left
**de-energized**; run `ticcmd --energize` before the next test. Every number
comes from the sources listed at the end.

The layout follows Cubware's
[`opentrons-pipette-setup.md`](https://github.com/Ursa-Laboratories/Cubware/blob/main/documentation/opentrons-pipette-setup.md)
diagram, with the TMC2209 swapped for a
[Tic T500](https://www.pololu.com/product/3134). The diagrams are generated by
[`_static/tic_t500_wiring.py`](./_static/tic_t500_wiring.py); edit the script
rather than the PNGs.

## Will the T500 do everything the pipette needs?

Yes, with one firmware constant to change. Nothing in the pipette's requirements
is outside the T500's specification.
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

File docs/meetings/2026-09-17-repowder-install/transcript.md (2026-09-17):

# rePowder BYU installation details — 2026-09-17 call

- **When:** Thursday 2026-09-17, 08:00–08:57 MDT (56 min)
- **Who:** Bartosz Kalicki (AMAZEMET), Dave Laws (BYU), Gage Erickson, Sterling Baird
- **Source:** Tactiq voice-to-text ([original](https://app.tactiq.io/api/2/u/m/r/cCdF7Qvts5v2gaqYv9ED?o=txt), raw copy in [`tactiq-raw.txt`](tactiq-raw.txt)). The transcript below is corrected for intent: mis-heard words fixed, stutters and filler turns dropped, timestamps kept. Corrections that change a number or a part are listed first so they can be checked against the raw file.

## Corrections worth knowing about
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

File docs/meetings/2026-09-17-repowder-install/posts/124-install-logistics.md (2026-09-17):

From the 9/17 call with Bartosz and Dave ([corrected transcript]({{TRANSCRIPT}})). Install is **Mon Sep 28**, training **Tue–Wed Sep 29–30**. Bartosz arrives Saturday and is flexible on hours.

@gage-erickson things to have ready before the 28th:
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

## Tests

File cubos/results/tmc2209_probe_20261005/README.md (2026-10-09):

# tmc2209_probe_20261005: the TMC2209 doesn't drive the plunger, so `pipette_test` was not run

Issue #169, 2026-10-05, CubXL Pi. Ben: *"run the pipette test protocol. I switched back to
the TMC2209 driver board to see if it would work."*

**It doesn't work, and `pipette_test` was not run.** Before CubOS homes the plunger, I
checked with the limit switch that the TMC2209 moves it and in which direction. With the
board plugged in, 9 mm of commanded travel in both directions never reached the switch.
A 30 s buzz at 100 full steps/s was then sent while Ben stood at the pipette, and he
reported *"nothing is happening with the pipette. No buzzing."* The Arduino sent every
step on schedule, so the fault is downstream of its `STEP`/`DIR` pins. Ben is putting the
pipette back on the Tic T500. The gantry never moved.

## Why probe before the protocol

- **The firmware is unchanged:** `panda_vcl_p20gen2_tic796_fastmove_20261001.hex`,
  796 steps/mm at 1/8 step. That suits a TMC2209 too. Its setup call writes 1/8 over
  UART, and if that write never lands, the MS1/MS2 straps default to 1/8 anyway
  ([wiring doc §10.3](../../docs/opentrons-pipette-wiring.md)).
- **Only the Tic's direction has ever been proven** ([2026-09-29](../pipette_switch_search_20260929/README.md)).
  The switch stops UP moves only. The firmware's `HOME` seeks UP blind for up to
  50,000 steps (~63 mm). On a reversed motor, CubOS's connect-time `HOME` would drive the
  plunger *down* into the tip ejector.

## Where the plunger started

The 2026-10-02 run ended with a `HOME` (12.698 s, `OK`), which leaves the plunger
796 steps (~1 mm) below the switch
([`pipette_test_20261002c`](https://github.com/vertical-cloud-lab/byu-vcl/blob/d921c64/cubos/results/pipette_test_20261002c/SUMMARY.md)).
A de-energized plunger stays put. The 09-30 `HOME` from the 09-29 resting place took 0.94 s,
which is a 1 mm seek plus the back-off. The switch read closed at the start of every
probe today, as it should.

## What the probes saw

400 microsteps/s unless stated. The millimetres are firmware millimetres
(796 microsteps/mm). A "switch read" sends 2 steps UP. The firmware refuses that while D9
reads open, whichever way the motor actually turns.

**Round 1, 22:01–22:05Z. The driver board was unplugged.** Ben had unplugged it because it
was heating up (his 22:10Z comment). So this round only shows that the Arduino side works.
His *"I'm unplugging the 12V"* comment came at 22:02:27Z, 25 s after the first probe ended,
so that probe may have run with the board still powered. It settles nothing either way.

| probe | UTC | commanded | seen |
|---|---|---|---|
| [`tmc2209_probe.py`](tmc2209_probe.py) ([log](probe.log)) | 22:01:55 | UP 3 mm, 0.5 mm chunks | no switch |
| [`tmc2209_probe_down.py`](tmc2209_probe_down.py) ([log](probe_down.log)) | 22:03:44 | DOWN 6 mm, 0.25 mm chunks, switch read after each | no switch |
| [`tmc2209_probe_up12.py`](tmc2209_probe_up12.py) ([log](probe_up12.log)) | 22:05:06 | UP 12 mm, 0.5 mm chunks | no switch |

**Round 2, 22:11–22:16Z. The board was plugged back in, and Ben reported it no longer
heating.**

| probe | UTC | commanded | if the motor turned | seen |
|---|---|---|---|---|
| `tmc2209_probe.py` ([log](probe2.log)) | 22:11:40 | UP 3 mm | the switch opens after ~1 mm | **no switch** |
| `tmc2209_probe_down.py` ([log](probe2_down.log)) | 22:12:00 | DOWN 6 mm, switch read every 0.25 mm | reversed: opens after ~4 mm | **no switch** |
| [`tmc2209_buzz.py`](tmc2209_buzz.py) ([log](buzz.log)) | 22:15:30–22:16:00 | 30 × (UP 0.5 mm, DOWN 0.5 mm) at 800/s = 100 full steps/s | a hum you can feel (Ben felt the Tic at these rates on 09-29) | **Ben: "No buzzing"** |

- **The Arduino side is fine.** Every move came back `OK` on schedule (1.015 s against
  0.995 s nominal per 0.5 mm), and the limit-switch input read normally.
- **`CMD 29` read `comm = 0` in both rounds.** There was no UART reply, so the driver's own
  fault flags (short, open load, over-temperature) couldn't be read.
- **The buzz settles it.** The switch probes alone leave one case open: a plunger moved
  more than ~3 mm down by hand. A person at the pipette closes it. 100 full steps/s
  for 30 s produced nothing Ben could feel or hear, so the board isn't driving the
  motor.
- **Heat.** Ben saw the board heat up before round 1, then stay cool once re-plugged. The
  pipette was warm too, so the hot board was driving coil current. See
  [Why it got hot](#why-it-got-hot-2026-10-06). *(Corrected 2026-10-06. This bullet first
  read the heat as heat without coil drive, from a damaged output stage. The warm pipette
  rules that out for the hot period.)*

## Why it got hot (2026-10-06)

Ben's follow-up on [PR #260](https://github.com/vertical-cloud-lab/byu-vcl/pull/260): why did the
board get so hot and then stop, did that break something, and did this session stop it? The
times come from his comments on #169, the logs here, and the file times on the Pi.

| UTC | |
|---|---|
| ~21:54 | The Pi boots (`Pi up 14 minutes` at 22:08:24). The Arduino is powered from its USB |
| 21:57:26 | Ben: the board is *"really warm (even with a heat sink on)"*, and the pipette is warm |
| 22:01:52 | The session's first contact with the Arduino: `tmc2209_probe.py` opens the port |
| 22:02:27 | Ben: *"I'm unplugging the 12V from the board"* |
| 22:08:28 | The checks-only pass opens the port |
| 22:10:30 | Ben: plugged in again and *"not heating up"* |
| 22:11:36–22:16:00 | Round 2 and the buzz: no motion |

**The session didn't cause the heat, and didn't set out to stop it.** The board was hot four
minutes before the session first opened the Arduino's port. After that it sent the Arduino only
`STATUS` (14), a cap-sensor read, `CMD 29` (a read), `CMD 16` moves and `EMAG_OFF` (6). None of
them sets the driver's current or switches it off. Pulling the 12 V at 22:02 is what stopped the
heat.

**The session may have kept it from coming back, though.** Each port open resets the Arduino, and
`setupPipette()` then re-sends the TMC2209's settings over UART. Those take the trimmer out of
circuit and set run current CS 6 (0.72 A rms on a 6121) and hold current CS 1 (0.21 A rms). That
happened seven times: 22:01:52, 22:03:41, 22:05:02, 22:08:28, 22:11:36, 22:11:56 and 22:15:26.
If the UART wire was connected and the 12 V was back on for one of them, the board idled at
0.21 A rms from then on and stayed cool. That can't explain the missing motion, since the same
settings drive 0.72 A rms during a move.

*Corrected 2026-10-06: they don't, and it can.* The library switches off StealthChop's automatic
current scaling, and the firmware never switches it back on. So CS 6 and CS 1 scale a fixed PWM
amplitude, about 0.1 A while moving and 0.03 A at rest, rather than setting a regulated current.
Cool, no motion and no buzz all follow from that one cause. See
[`tmc2209_probe_20261006`](../tmc2209_probe_20261006/README.md) and wiring doc §24.

**Why it got hot: it held the motor at a current nobody had set.**

- The driver is on whenever it has 12 V. The firmware drives A4 (`EN`) low, and the 6121 pulls
  `EN` down with 20 kΩ as well, so the coils carry current with nothing moving. The warm pipette
  shows they did.
- The firmware's settings reach the chip only when the Arduino resets with the 12 V already up.
  Before 22:01:52 the last reset was at ~21:54 or earlier. If the 12 V came on after it, the chip
  was in standalone mode, and the trimmer set the current: up to ~1.5 A rms (2.2 A peak) at full
  clockwise on a 6121 (wiring doc §22.5a), against the P20's 1.0 A peak.
- In standalone mode it also held that full current at rest. The chip drops to its hold current
  only while `PDN_UART` is low ([datasheet][tmc2209-ds] §3.4), and the UART line from A1 idles
  high. So the hold current was the run current.

Nobody has measured where the new board's trimmer sits, so the current isn't known. For
scale, the datasheet's typical dissipation is 1.4 W at 1.0 A rms and 2.8 W at 1.4 A rms
(datasheet §20.3). Near the top of that range a small breakout gets too hot to touch, heat
sink or not, and the motor takes up to about five times the Tic's 4 W.

**Why it then stayed cool:** either the settings landed (above) and something else stops the
motion, or no coil current has flowed since the re-plug. The second covers "cool", "no motion"
and "no buzz" with one cause: no 12 V at the VM terminals, no VDD, or a driver that no longer
drives.

**Whether it broke:** unknown until it is measured (the checklist below). Heat alone is the
less likely culprit. The chip switches its outputs off at 143 °C and back on below 120 °C
(datasheet §15.1). At the trimmer's top end (~1.5 A rms) it runs just past its 1.4 A rms
continuous rating (datasheet §20.1), the kind of slow overload that cutoff is for. More likely
ways to break it are how the 12 V went back in (see *Every step* below) and a motor wire moving
while powered. The motor came through: on 2026-10-06 the same pipette ran `pipette_test` 12/12
on the Tic with no lost steps.

[tmc2209-ds]: https://github.com/janelia-arduino/TMC2209/blob/main/datasheet/TMC2209_datasheet_rev1.09.pdf

## Why the protocol was not run

With a plunger that doesn't move, CubOS's `HOME` on connect runs out its 50,000 steps
(~26 s) and fails. The patched connect carries on regardless. The run would pick up a tip,
fail to eject it, and finish with the tip stuck. That adds nothing about the driver and
leaves a tip to pull off by hand. Until the switch has proven the direction, a blind `HOME`
is also the one command that can drive a reversed plunger into the ejector.

Everything else was ready. A checks-only pass of `cubxl_run.py` at 22:08Z
(`~/cubxl_runs/checks_20261005/` on the Pi) used Ben's 10-02 files
(`cub_xl_ben_3_instrument.yaml`, `ben_2vials_tiprack.yaml`) and found:

- GRBL matches the gantry file: travel 364 / 281 / 125, `G54` = −travel, `$20=1`, `$21=1`.
- The Arduino answers, the cap sensor reads 0, and the magnet is off.
- The validate, mock and both collision-shadow gates pass.

Nothing moved. Opening the GRBL port resets the controller into `Alarm`, as every run does,
and the protocol's step 0 `home` clears it.

## If the TMC2209 is tried again

*Rewritten 2026-10-06 as a troubleshooting checklist, at Ben's request.* The first version
asked whether this was the 6121 condemned on 2026-09-26. Ben said at 22:06Z that it is a new
board. It also said the UART wire only mattered for readback, which is wrong: it carries the
firmware's current settings.

*2026-10-06: Ben's run through steps 1–12 and the probe's result are in
[`tmc2209_probe_20261006`](../tmc2209_probe_20261006/README.md).* The board passed. Step 13's
"0.21 A rms hold current" below is wrong for the reason given there. Once the firmware's writes
land, the chip holds ~0.03 A and should feel cold. The last two rows of the table now lead to
that record's tests A and B.

Section numbers are from [`opentrons-pipette-wiring.md`](../../docs/opentrons-pipette-wiring.md).
The figures assume an Adafruit 6121 like the 09-26 board: 0.05 Ω sense resistors, VREF at most
~1.16 V. *(Ben confirmed on 2026-10-07 that the new board is a 6121.)* Header pins (§10.3): 1 VDD, 2 GND, 3 DIR, 4 STEP, 7 DIAG, 9 UART, 10 EN. The pipette
works on the Tic, so steps 1–13 can also be done on the bench with a spare stepper, which
leaves the CubXL alone.

**Every step:** switch the 12 V on and off at the wall (or the supply's own switch), with its
DC lead already connected to the board. The datasheet wants VS to rise slower than 1 V/µs:
*"failure to do so could result in destructive currents via the charge pump capacitor"*
([datasheet][tmc2209-ds] §3.1). Pushing a live lead in can be far faster. Touch motor wires
only with the 12 V off.

**Power off**

1. Look the board over: discolouration or a crack near the chip, a burnt smell, and the heat
   sink on the chip only.
2. Resistance across the VM terminals, red probe on `+`, black on `−`. It should climb as the
   22 µF capacitor charges. Steady under ~10 Ω means a shorted chip or capacitor: replace the
   board.
3. Coils at the board's terminals: 1A–1B and 2A–2B about 4 Ω (4.3 / 3.7 Ω on 09-23). 1A–2A and
   1B–2B open.
4. Lift the four motor wires. Diode-test each of 1A, 1B, 2A and 2B against GND and against VM+,
   both ways round (§22.7): about 0.4–0.6 V one way, alike on all four. ~0.00 V is a shorted
   output, and open is a dead one. Reconnect the wires.
5. Beep out the wiring from the Arduino to the header: 5V–1, GND–2, A3–3 (DIR), A2–4 (STEP),
   A1–9 (UART, with the 10 kΩ to A0), A4–10 (EN), and the 12 V supply to the VM block. The swaps
   to the Tic and back are where a wire is most likely to have gone astray.
6. Take EN (pin 10) off A4 and jumper it to the Arduino's 5V. Then the chip passes no coil
   current, whatever its trimmer says (§22.8 step 4).

**12 V on, EN high.** Black probe on GND.

7. VM at the screw heads: 11.4–12.6 V. 0 V means it isn't connected, and −12 V means it is
   reversed.
8. VDD (pin 1): about 5 V, never 12 V. Without it the chip is held in reset (datasheet
   §20.2). The green LED also needs VDD: it lights while DIR is low.
9. VREF at the trimmer wiper (§19.4). Anything above 0 V means the chip's internal 5 V regulator
   is alive. About 0 V with VM present means a dead chip: replace the board. Set it to
   0.55–0.59 V, about 1.0 A peak, the same current the firmware asks for (§22.4).
10. DIAG (pin 7): about 0 V.
11. After a minute, the chip should still be at room temperature. If it warms with EN high, stop.

**Enable it**

12. Move EN back to A4. DIAG should stay near 0 V. If it jumps to ~5 V, switch off and stop: the
    output stage is failing its own short check, as the 09-26 board did (§22.2).
13. With nothing commanded, the chip and the pipette get warm, not hot. At VREF 0.55 V it holds
    ~0.72 A rms at rest, about the Tic's 4 W in the motor, until an Arduino reset lands the
    firmware's 0.21 A rms hold current. A gently pushed plunger should resist (§22.7).
14. Run [`tmc2209_probe.py`](tmc2209_probe.py) (below). Its port open is that reset. It proves
    the direction with the limit switch before any `HOME`.
15. Optional: move the 10 kΩ to the TX side (§22.8 step 2). Then `CMD 29` reads the chip's own
    flags (short, open load, over-temperature) instead of `comm = 0`.

| finding | meaning |
|---|---|
| VM wrong (7) | fix the 12 V wiring and start again |
| VDD missing (8) | connect the Arduino's 5V to pin 1 and start again |
| VREF ~0 V with VM present (9) | dead chip: replace the board |
| DIAG high once enabled (12) | damaged output stage: replace the board |
| holds at 13, but the probe sees no motion | take the UART wire off pin 9 and run the probe again. If it moves now, the UART writes leave the driver off (§4). If not, STEP isn't reaching pin 4 |
| the probe proves the direction | the 10-05 fault was the wiring or the 12 V connection |

**Order of operations.** Run [`tmc2209_probe.py`](tmc2209_probe.py) first. Once the
switch proves the direction, it also runs a rate ladder (1,000 / 2,500 / 10,000 steps/s,
the last being the rate `MOVE_TO` and `ASPIRATE` use) and a `HOME`. After that, run
`cubxl_run.py --no-tic` with the 10-02 files. Without `--no-tic`, the runner's Tic check
refuses to start.

```bash
cd ~/cubxl_runs/tmc2209_probe_20261005 && \
  PYTHONPATH=$HOME/CubOS/packages/core/src ~/CubOS/.venv/bin/python tmc2209_probe.py tmc2209_probe.json
```

## State left

- **Plunger:** not homed. Nothing turned it today, so it should still be where 10-02 left
  it, ~1 mm below the switch.
- **Electromagnet:** off, `EMAG_OFF` → `OK` after every probe.
- **Gantry:** not moved. It hasn't been homed since the 15:54 lab-time boot. GRBL is in
  `Alarm` from the checks-only port open.
- **Driver:** Ben is putting the pipette back on the Tic T500. The runner's Tic path,
  without `--no-tic`, re-checks the Tic's settings and energizes it before a run, as on 10-02.
  *(2026-10-06: done. `pipette_test` ran 12/12 on the Tic.)*
- **Pi:** dropped off the tailnet at ~22:17Z, presumably powered down for the swap, and
  was still offline at 22:36Z.
- **`~/cubxl_runs/HOLD` was left on the Pi.** It held the CubXL for this session
  (Actions run 37379090191), and the Pi went offline before the session could remove
  it. *(2026-10-06: the next run session replaced it with its own and then removed that.
  There was no `HOLD` on the Pi at 21:53Z.)*
- The round-2 and buzz logs here were copied from the session's terminal, since the Pi was
  offline at write-up. The matching `*.json` row files, and `runner.log` / `gate_*.log` for
  the checks-only pass, are on the Pi under `~/cubxl_runs/`.

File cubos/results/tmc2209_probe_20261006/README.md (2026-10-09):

# tmc2209_probe_20261006: no motion again, and the firmware's driver setup is the likely cause

Issue #169, [PR #260](https://github.com/vertical-cloud-lab/byu-vcl/pull/260), 2026-10-06,
CubXL Pi. Ben worked through the checklist in
[`tmc2209_probe_20261005`](../tmc2209_probe_20261005/README.md#if-the-tmc2209-is-tried-again),
then: *"run tmc2209_probe.py"*.

**The plunger didn't move in either direction, so there was no `HOME`.** Reading the
firmware's TMC2209 library and the datasheet turned up a likely cause, and it isn't the
board. The library switches off the chip's automatic current control, and the firmware never
switches it back on. That leaves the coils with about **0.1 A** when they should get 1 A
([below](#why-it-doesnt-move-the-chip-is-asked-for-about-a-tenth-of-the-current)). This is a
reading of the source, not yet a measurement. [Next](#next-two-ways-to-test-it) gives two ways
to test it.

*(2026-10-07: test A done. With the UART wire off pin 9, the board went from cold to warm, and
`tmc2209_probe.py` proved the direction, passed the whole rate ladder and homed:
[`tmc2209_probe_20261007`](../tmc2209_probe_20261007/README.md).)*

## What the probes saw

Both scripts are the 10-05 ones, unchanged: the same sha256 on the Pi and in
[`../tmc2209_probe_20261005/`](../tmc2209_probe_20261005/). Plunger only. The GRBL port was
never opened.

| probe | UTC | commanded | seen |
|---|---|---|---|
| [`tmc2209_probe.py`](../tmc2209_probe_20261005/tmc2209_probe.py) ([log](probe.log), [json](tmc2209_probe.json)) | 22:46:14 | UP 3 mm in 0.5 mm chunks at 400 microsteps/s | **no switch**, exit 1, no `HOME` |
| [`tmc2209_probe_down.py`](../tmc2209_probe_20261005/tmc2209_probe_down.py) ([log](probe_down.log), [json](tmc2209_probe_down.json)) | 22:52:01 | DOWN 6 mm in 0.25 mm chunks, switch read after each | **no switch**, so the motor isn't running backwards |

- **The Arduino side is normal.** Every move came back `OK` on schedule (1.015–1.016 s per
  0.5 mm against 0.995 s nominal). The switch read closed (below the top) at the start.
  `EMAG_OFF` → `OK`.
- **`CMD 29` read `comm = 0`.** The 10 kΩ is still on the RX side, so there's no readback.
- **No USB events** during either probe.
- **The plunger should still be ~1 mm below the switch.** On 10-05, with this board plugged
  in, it was sent DOWN 6 mm, a direction the switch doesn't stop. Yet the 10-06 Tic run's
  connect `HOME` took 0.94 s, a 1 mm seek, so that move turned nothing either. The 10-06 run's
  own closing `HOME` left the plunger 1 mm below the switch.

## Ben's readings, steps 1–12

| step | reading | verdict |
|---|---|---|
| 1 look | normal | ✅ |
| 2 VM terminals, ohms | rises as the capacitor charges | ✅ no short |
| 3 coils | 1A–1B and 2A–2B 3.4 Ω, cross pairs very high | ✅ (4.3 / 3.7 Ω on 09-23) |
| 4 diode test | ~1.5 V on each, *"the same both ways around"* | ❓ below |
| 7 VM | 12.4 V | ✅ |
| 8 VDD | 5 V | ✅ |
| 9 VREF | 0.586 V | ✅ `5VOUT` alive; 1.09 A peak on a 6121, *in standalone mode only* (below) |
| 10 DIAG, EN high | 0 V | ✅ |
| 12 DIAG, EN back on A4 | 0 V | ✅ **the go/no-go the 09-26 board failed** |

Steps 5, 6, 11 and 13 weren't reported. Step 6 must have been done, since step 12 moved EN back.

**The diode test isn't the expected result, but it doesn't change the next step.** A healthy
output reads 0.4–0.6 V one way round. 1.5 V both ways round was also what the 09-26 board gave
(wiring doc §22.1). Two cheap explanations come before a fault:

- The probes were on the lifted wire ends. Ben wrote *"on each motor wire"*. The wire ends are
  open circuit. The board's `1A`/`1B`/`2A`/`2B` terminals are what to test.
- The meter shows about 1.5 V for an open circuit in diode mode. Check this with the probes
  touching nothing.

DIAG staying at 0 V once enabled is the stronger evidence. The chip checks every output MOSFET
it switches on, and the old board failed exactly that check.

## Why it doesn't move: the chip is asked for about a tenth of the current

The flashed image is `panda_vcl_p20gen2_tic796_fastmove_20261001.hex`. Its source is
`~/panda_fw_vcl_tic796_fast` on the Pi, built against
[janelia-arduino/TMC2209](https://github.com/janelia-arduino/TMC2209) **10.1.1**.
`setupMotor()` runs on every Arduino reset:

```
stepperDriver.setup(softSerial)  -> TMC2209::initialize():
    setOperationModeToSerial()           GCONF: i_scale_analog 0 (trimmer out of circuit),
                                                pdn_disable 1, mstep_reg_select 1
    setRegistersToDefaults()             PWMCONF = 0xC10D0024: PWM_OFS 36, PWM_GRAD 0,
                                                pwm_autoscale 1, pwm_autograd 1
    clearDriveError(); minimizeMotorCurrent(); disable()
    disableAutomaticCurrentScaling()     PWMCONF.pwm_autoscale = 0   <- never undone
    disableAutomaticGradientAdaptation() PWMCONF.pwm_autograd  = 0
setRunCurrent(20)                        IRUN 6
setHoldCurrent(5)                        IHOLD 1
setMicrostepsPerStep(8)                  MRES 1/8
enableStealthChop()                      en_SpreadCycle 0; TPWMTHRS is 0, so StealthChop at every speed
enableCoolStep()                         inert: TCOOLTHRS is 0
enable()                                 CHOPCONF.toff 3
```

The [datasheet][tmc2209-ds]'s PWMCONF table explains what `pwm_autoscale = 0` does:
*"User defined feed forward PWM amplitude. The current settings IRUN and IHOLD are not enforced
by regulation but scale the PWM amplitude, only! The resulting PWM amplitude (limited to
0…255) is: PWM_OFS * ((CS_ACTUAL+1) / 32) + PWM_GRAD * 256 / TSTEP"*.

So the chip doesn't regulate the current at all. It applies a fixed fraction of VM:

| | CS | PWM amplitude, of 255 | coil current at 12.4 V, 3.4 Ω |
|---|---|---|---|
| moving | IRUN 6 | 36 × 7/32 ≈ 7.9 | **≈ 0.08 A rms (0.11 A peak)** |
| at rest | IHOLD 1 | 36 × 2/32 ≈ 2.3 | **≈ 0.02 A rms (0.03 A peak)** |
| what `RUN_CURRENT_PERCENT 20` was meant to give | IRUN 6 | would need ≈ 74 | 0.72 A rms (1.02 A peak) |
| the Tic, which moves this plunger at every rate | | regulated | 0.99 A limit |

The currents come from the datasheet's own formula for this mode (§6.4, p. 43):
`I_rms = VM × PWM_SCALE / (374 × R_coil)`. Back-EMF in motion lowers them further. A tenth of
the rated current gives about a tenth of the torque. That's too little to drive the plunger past
its seals, and it's silent and cold while it fails.

**It fits everything seen so far:**

| observation | explanation |
|---|---|
| 10-05: the board was hot before the session first opened the port | no UART writes had landed: standalone mode, where StealthChop's automatic scaling *does* regulate, to the trimmer's current |
| 10-05: cool after the port opens, and ever since | the writes landed: ~0.03 A at rest |
| no motion either way on 10-05 or today; no buzz at 100 full steps/s | ~0.1 A while moving |
| DIAG low when enabled | nothing is wrong with the output stage. It just isn't asked for current |
| every move `OK` on schedule | the Arduino side was never at fault |

It applies to every image this TMC2209 path has run. Upstream's `RUN_CURRENT_PERCENT 50`
(CS 15) gives 36 × 16/32 = 18, about 0.23 A, and the 09-15 image's 17 (CS 5) about 0.09 A. The
09-26 board still had a fault of its own (DIAG high once enabled).

**Corrections to the 10-05 record and wiring doc §22.** These all assumed the firmware's
settings drive their nominal current. They don't, in this mode:

- *"the same settings drive 0.72 A rms during a move"*
- the 0.21 A rms hold current
- §22.4–§22.5b: *"the two agree within 7%, so it stops mattering"*

Once the writes land, the trimmer is out of circuit and the current is ~0.1 A, whatever VREF
says.

**Not yet shown.** All of this depends on the UART writes landing. The 10-05 hot-then-cool
sequence suggests they do, but `comm = 0` can't confirm it. If they don't, the chip is in
standalone mode, the trimmer governs, and something else stops the motion. The most likely
culprit is then `STEP` not reaching header pin 4. Test A below separates the two.

[tmc2209-ds]: https://github.com/janelia-arduino/TMC2209/blob/main/datasheet/TMC2209_datasheet_rev1.09.pdf

## Next: two ways to test it

**Free check first.** With the 12 V on and nothing moving for a few minutes, the chip and
pipette should be **cold** if this is right, since the hold current is ~0.03 A. If they're
**warm**, the chip is in standalone mode holding the trimmer's ~0.77 A rms, so the writes
aren't landing and the cause is elsewhere.

**A. No firmware change: take the UART wire off.** Takes about two minutes at the bench.

1. Switch off the 12 V. Take the UART wire (A1) off header pin 9 and leave everything else.
2. Switch on the 12 V. The firmware's writes now go nowhere, and the chip runs in standalone
   mode: StealthChop with automatic scaling, the trimmer's current (VREF 0.586 V ≈ 0.77 A rms
   on a 6121), and 1/8 step from MS1/MS2, which matches 796 steps/mm. After a minute, it and
   the pipette should be warm.
3. Comment `@claude run tmc2209_probe.py`.

| result | meaning |
|---|---|
| direction proven, `HOME` ok | the firmware setup was the fault. Standalone mode can stay: it's the Tic's arrangement, full current at rest, set by the trimmer. Or put the wire back after fix B |
| no motion, board warm | current flows but `STEP` doesn't arrive: beep A2 → pin 4 |
| no motion, board cold | no coil current even in standalone mode: back to the board |

**B. Fix the firmware.** No hands needed, but it needs Ben's go-ahead, because the same Arduino
runs the capper. In `src/Pipette.cpp`, `setupMotor()`:

```diff
-    stepperDriver.enableStealthChop();
+    stepperDriver.disableStealthChop();   // [VCL] SpreadCycle: IRUN/IHOLD regulated
```

SpreadCycle regulates the coil current every chopper cycle against the sense resistors, like
the Tic. IRUN 6 then means 0.72 A rms (1.02 A peak) and IHOLD 1 means 0.21 A rms, on a 6121's
0.05 Ω. It also tolerates the firmware's step changes in speed: `stepMotor()` starts at up to
~8,700 microsteps/s with no ramp, and StealthChop's automatic tuning expects ramped moves. Staying in
StealthChop and calling `enableAutomaticCurrentScaling()` and
`enableAutomaticGradientAdaptation()` is quieter, but needs tuning moves. With the Tic in
circuit the writes reach nothing, so B doesn't change the Tic path. Build it, flash it with
`avrdude -U flash:v` before and after, as in the [firmware README](../../firmware/README.md),
then run `tmc2209_probe.py`.

Whichever way it moves, run the probe before any protocol, and use `cubxl_run.py --no-tic`.

## The USB over-current at 16:35 lab time

The Pi's kernel log had nothing to do with the probes, but it's worth knowing about:

| UTC | |
|---|---|
| 22:15:07 | the Tic unplugged (the swap) |
| 22:26:07, 22:33:42, 22:34:33, 22:34:57 | the GRBL board's CH340 drops off USB and comes back, with no over-current |
| **22:35:04–09** | **over-current on every USB port at once**, ~96 events. The Arduino and the CH340 both drop and come back |
| **22:35:31–32** | again, 23 events, and both drop and come back again |

Nothing since: `throttled=0x0`, EXT5V 5.13 V. The timing matches the bench work. The likely
cause is the Arduino's `5V` header pin, which sits between `3.3V` and `GND`. A jumper or probe
that slips there during step 6 or step 12 shorts the USB 5 V, and the Pi switches off every
port. A run on 09-30 was stopped the same way. It's harmless if brief, but every drop resets the
Arduino (dropping the capper's magnet) and GRBL (so it needs homing).

## State left

- **Plunger:** not homed, and most likely still ~1 mm below the switch, since nothing turned.
  *(2026-10-07: it was 1.65 mm below. Something moved it ~0.65 mm down.)*
- **Electromagnet:** off, `EMAG_OFF` → `OK` after each probe.
- **Gantry:** not touched, and its port wasn't opened. GRBL was reset by the 16:35 USB drops,
  so it needs homing before a run, as always.
- **`~/cubxl_runs/HOLD`:** written for this session at 22:46Z and removed at 22:53Z.
- **On the Pi:** `~/cubxl_runs/tmc2209_probe_20261006/` holds these logs and copies of the
  two scripts.

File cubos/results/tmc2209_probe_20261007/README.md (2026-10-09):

# tmc2209_probe_20261007: with the UART wire off, the TMC2209 moves the plunger at every rate

> **Correction, later on 2026-10-07.** The wire that came off was **EN (from A4)**, not the
> UART wire. Ben: *"I realized I unplugged EN from A4 instead of UART."* So this run had the
> UART wire on pin 9 the whole time. EN is low either way (the firmware drives A4 low, and the
> 6121 pulls EN down), so the pass below can't be put down to the wire that was pulled. For
> the StealthChop image to move the plunger, its writes can't have reached the chip in this
> run, for a reason nothing recorded shows. With EN back on and everything plugged in, the
> same image didn't move it twice, and fix B (`disableStealthChop()`) then ran `pipette_test`
> 12/12. See [`tmc2209_spreadcycle_20261007`](../tmc2209_spreadcycle_20261007/README.md).
> The text below is as written before the correction. Its "pin 9 now floats" advice no longer
> applies.

Issue #169, [PR #260](https://github.com/vertical-cloud-lab/byu-vcl/pull/260), 2026-10-07,
CubXL Pi. Ben did the free check and test A from
[`tmc2209_probe_20261006`](../tmc2209_probe_20261006/README.md#next-two-ways-to-test-it):
*"The board and pipette were cold. I unplugged UART from pin 9. The board is getting warm."*,
then *"run tmc2209_probe.py"*.

**It moved, at every rate the firmware uses, and `HOME` worked.** `tmc2209_probe.py` exited
0. UP opened the limit switch after ~1.65 mm, every rung of the rate ladder reopened it after
its 2 mm back-off, and the firmware `HOME` returned `OK`. The same board was cold and didn't
move with the UART wire on, and is warm and moves with it off. So the board is fine, and the
firmware's UART setup was what stopped it, as 10-06 predicted.

## What the probe saw

[`tmc2209_probe.py`](../tmc2209_probe_20261005/tmc2209_probe.py), unchanged: the same sha256
(`58cb6aab…`) on the Pi as in the repo. [Log](probe.log), [rows](tmc2209_probe.json).
18:18:13–18:18:41Z. Plunger only. The GRBL port was never opened.

| step | sent | seen |
|---|---|---|
| connect | port open, which resets the Arduino | connected in 3.77 s, `STATUS` `homed 0` |
| `CMD 29` | driver status | `comm = 0`, as expected with nothing on pin 9 |
| switch read | 2 steps UP | closed (below the top) |
| UP search | 0.5 mm moves at 400 microsteps/s | moves 1–3 completed. **Move 4 opened the switch after ~0.15 mm**, ~1.65 mm in all |
| ladder @ 1000 | DOWN 2 mm at 400/s, then UP 4 mm at 1,000/s | switch reopened after ~2.05 mm |
| ladder @ 2500 | the same at 2,500/s | ~2.12 mm |
| ladder @ 10000 | the same at 10,000/s, ~8,700/s in practice: the rate `MOVE_TO` and `ASPIRATE` use | ~2.13 mm |
| `HOME` | DOWN 2 mm, then cmd 10 | `OK:{"msg":"Pipette homed"}` in 1.348 s. `homed 1`, `pos 0.00`, switch closed |
| end | `CMD 29`, `EMAG_OFF` | `comm = 0`. `OK` |

- **DIR LOW is up,** as on the Tic. The firmware's blind `HOME` seek is safe with this board
  as wired.
- **No lost steps at any rate.** Each rung backs off 1,592 microsteps and times how long it
  takes to reopen the switch. A start the motor didn't follow would show up as extra
  distance. The small rise with rate, 2.05 to 2.13 mm, comes from the timing estimate, not
  the motor. The Tic showed the same rise on 09-29
  ([`pipette_switch_search_20260929`](../pipette_switch_search_20260929/README.md), same
  method and the same raw step counts). At 2,500/s the trip took 0.774 s here and 0.770 s on
  the Tic. `HOME` from 2 mm below took 1.348 s here and 1.356 s on the Tic.
- **It started 1.65 mm below the switch, not the ~1 mm the 10-06 record expected.** Something
  moved it ~0.65 mm down after the Tic's last `HOME` on 10-06: a hand on the plunger, or the
  10-06 probes turning it part of the way. `HOME` has re-zeroed it.
- *Added later that day:* Ben at 18:19:13Z, half a minute after the probe ended: *"I felt the
  pipette vibrating, but it was pretty light."*

## What it settles

| question | answer |
|---|---|
| did the 10-05 heat damage the board? | no. It drives the motor at every rate |
| do `STEP` and `DIR` reach it? | yes |
| which way is up? | DIR LOW, as on the Tic |
| why no motion on 10-05 and 10-06? | the firmware's UART writes. They land, and leave the chip too weak to move: cold with the wire on, warm and moving with it off |

**What it doesn't settle.**

- **Which written setting starves the motor.** That's still read from the library source
  ([10-06](../tmc2209_probe_20261006/README.md#why-it-doesnt-move-the-chip-is-asked-for-about-a-tenth-of-the-current)),
  not read back from the chip. Nothing can be read back while the 10 kΩ is on the RX side,
  and now the wire is off as well.
- **The step size.** Every figure here is a step count. 1/8 step is what `MS1`/`MS2` give with
  nothing on them (internal pull-downs, wiring doc §10.3), and it matches 796 steps/mm, but
  nothing here measures it.

## Why it's warm now

With the wire off, the firmware's writes go nowhere, and the chip runs on its own pins
(standalone mode):

- **Current from the trimmer.** VREF 0.586 V is ≈ 0.77 A rms (1.09 A peak) on a 6121's 0.05 Ω
  sense resistors. Ben hasn't confirmed the new board is a 6121. *(He did later that day: it
  is.)*
- **StealthChop with automatic current regulation,** if the board leaves `SPREAD` on its
  internal pull-down.
- **1/8 step** from `MS1`/`MS2`.

It keeps current in the coils at rest. That's the Tic's arrangement: on 09-29 the Tic held
990 mA, about 4 W into the pipette body, with nothing running. So warm is what test A
predicted. There's no software off switch in this mode, so the 12 V switch is the way to stop
it holding when the CubXL is idle.

**Pin 9 now floats.** The [datasheet][tmc2209-ds]'s pin table gives `PDN_UART` no internal pull
(`DIO`, where `MS1`, `MS2`, `SPREAD` and `DIR` are `DI (pd)`). The 6121 notes in wiring doc
§10.3 list no board pull either. That pin decides the current at rest: low cuts it to `IHOLD`,
53% of the run current by the OTP default; high keeps the full run current. Floating, it's
whichever way the pin drifts. That's harmless, but if the wire stays off for good, give pin 9 a
level through 1–10 kΩ: to pin 2 (GND) for the cooler reduced hold, or to pin 1 (VDD) for the
Tic's full hold. The resistor keeps a stray A1 wire from shorting the Arduino pin. Rerun the
probe after.

If the pipette gets hotter than it did on the Tic, VREF 0.54 V gives 1.0 A peak, the P20's
rating. 0.586 V is 9% over it. Rerun the probe after that too.

[tmc2209-ds]: https://github.com/janelia-arduino/TMC2209/blob/main/datasheet/TMC2209_datasheet_rev1.09.pdf

## Next

1. **`pipette_test` with the wire off.** Use `cubxl_run.py --no-tic` with the 10-02 files, per
   the [10-05 order of operations](../tmc2209_probe_20261005/README.md#if-the-tmc2209-is-tried-again).
   It moves the gantry, so it waits for Ben's go-ahead.
2. **Then pick how to keep it:**
   - **Wire off for good.** This is what ran today, and it's the Tic's arrangement. Tie pin 9
     to a level as above.
   - **Fix B, wire back on.** `disableStealthChop()` in `setupMotor()`
     ([10-06](../tmc2209_probe_20261006/README.md#next-two-ways-to-test-it)). The firmware then
     sets a regulated 0.72 A rms moving and 0.21 A rms at rest, so it idles cool. It needs a
     flash of the Arduino that also runs the capper, and the probe again.

## State left

- **Plunger:** homed, 796 microsteps (1 mm) below the switch, `pos 0.00`. The next port open
  resets the Arduino and clears `homed`. CubOS re-homes on connect.
- **Electromagnet:** off, `EMAG_OFF` → `OK`.
- **Gantry:** not touched, and its port wasn't opened.
- **Driver:** TMC2209 in standalone mode, UART wire off pin 9, VREF 0.586 V, 12 V on, holding
  current at rest.
- **`~/cubxl_runs/HOLD`:** written for this session at 18:18:07Z and removed at 18:18:54Z.
- **Pi:** up 21 h, `throttled=0x0`, EXT5V 5.13 V. No kernel log entries since 10-06 22:50Z, so
  no USB drops during Ben's rewiring.
- **On the Pi:** `~/cubxl_runs/tmc2209_probe_20261007/` holds the log, the JSON and copies of
  both scripts.

To rerun:

```bash
cd ~/cubxl_runs/tmc2209_probe_20261007 && \
  PYTHONPATH=$HOME/CubOS/packages/core/src ~/CubOS/.venv/bin/python tmc2209_probe.py tmc2209_probe.json
```

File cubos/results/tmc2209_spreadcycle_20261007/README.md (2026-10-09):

# tmc2209_spreadcycle_20261007: with fix B, the TMC2209 runs `pipette_test` 12/12 with everything plugged in

Issue #169, [PR #260](https://github.com/vertical-cloud-lab/byu-vcl/pull/260), 2026-10-07,
CubXL Pi. Ben: *"Try the probe test as is, and if it doesn't work, I want to try fix B so we
can leave everything plugged in when idle. flash the spreadCycle fix, and if the probe test
comes back successful, run the pipette test. I realized I unplugged EN from A4 instead of
UART. I just plugged EN back in to A4."*

**It worked.** With EN back on A4 and the UART wire on pin 9, the 10-01 firmware didn't move
the plunger, in two probes. Fix B (`disableStealthChop()`) did. `tmc2209_probe.py` passed, then
`pipette_test` ran 12/12 with no lost steps. Its plunger timings match the Tic's 10-06 run to
the hundredth of a second. Afterwards Ben confirmed that the board is an Adafruit 6121, and
found it at room temperature at idle. That is the sign that the firmware's hold current is in
force, not the trimmer's ([Ben's follow-ups](#bens-follow-ups)).

## Timeline (UTC)

| time | what | result |
|---|---|---|
| 18:33:10 | Both USB devices drop off the Pi and re-enumerate within 2 s, so the Arduino reset. Ben's *"I just plugged EN back in to A4"* came at 18:34:24 | |
| 18:40:05 | run 37667869310, on Ben's first version of the comment: the probe as is ([log](baseline_probe.log)) | no switch within 3 mm UP |
| 18:41:00 | that run is cancelled by the comment edit. It had written `HOLD`, and flashed nothing | |
| 18:49:52 | this run: the probe as is ([log](asis_probe.log)) | no switch within 3 mm UP |
| 18:51:48 | build ([script](build_spreadcycle.sh), [log](build.log)) | the unedited copy rebuilds to the 10-01 image byte-for-byte |
| 18:52:15 | flash ([script](flash_spreadcycle.sh), [log](flash.log)) | 10-01 image matched before, fix B matched after |
| 18:52:54 | the probe on fix B ([log](spread_probe.log)) | **exit 0** |
| 18:55:08–18:57:25 | [`pipette_test_20261007`](../pipette_test_20261007/SUMMARY.md) | **12/12** |
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

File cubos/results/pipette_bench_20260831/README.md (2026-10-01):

# Plunger bench test — 2026-08-31

Ran `cubos/tools/pipette_bench_check.py` against the CubXL's Arduino at
@benwhitney5463's request, plus two follow-up probes the tool's own output
made necessary. **No protocol was run and no gantry motion was commanded** —
the only hardware actuated was the pipette plunger.

Also this session: `patches/tipped-hover-clamp-and-ceiling-travel.patch` was
applied to `~/CubOS` on the Pi, and the 2026-08-31 rev-2 config trio was
validated offline against it.

---

## Verdict

**The plunger stepper only ever turns one way.** The serial link is healthy,
the firmware parses every command, and the motor is genuinely driven — but
only in the direction of increasing `pos`. Every command that would retract
the plunger returns `OK` in ~0.11 s and does nothing.
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

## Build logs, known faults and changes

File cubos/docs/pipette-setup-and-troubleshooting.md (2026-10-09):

# The Opentrons P20 on the CubXL — setup and troubleshooting

Status as of **2026-10-07**. This is the map; the detail is in
[`opentrons-pipette-wiring.md`](./opentrons-pipette-wiring.md), which is the
durable technical record and is where new findings go.

The pipette is an **Opentrons P20 GEN2** single-channel, mounted on the CubXL
gantry beside the capper/decapper and driven by an **Adafruit 6121 TMC2209**
breakout off an **Arduino Uno R3**. CubOS speaks to that Arduino over
`/dev/ttyACM0`, which it shares with the capper's electromagnet and line-break
sensor. The gantry is a separate stepper system on `/dev/ttyUSB0` — see §15 of
the wiring doc, because conflating the two has cost real time.

## Where it stands

> ✅ **2026-10-07, later: fix B is flashed, and `pipette_test` ran 12/12 on the TMC2209 with
> every wire on.** The wire pulled for the earlier entry was EN from A4, not UART. With EN back
> on, the 10-01 image didn't move the plunger in two probes. The firmware was rebuilt with
> `disableStealthChop()` in `setupMotor()`, which changes one instruction (GCONF
> `en_SpreadCycle`), and flashed. `tmc2209_probe.py` then passed, and `cubxl_run.py --no-tic`
> ran 12/12 with a post-run `HOME` of +0.04 mm. Its plunger timings match the Tic's 10-06 run.
> The chip now runs on the firmware's regulated current, 0.72 A rms moving and 0.21 A rms at
> rest on a 6121 (Ben has confirmed the new board is one), so everything can stay plugged in at
> idle. Ben found the board at room temperature at idle after the run, the sign that the
> firmware's settings are in force rather than the trimmer's. Run with `--no-tic` while the
> TMC2209 is on. Record:
> [`tmc2209_spreadcycle_20261007`](../results/tmc2209_spreadcycle_20261007/README.md), wiring
> doc §26, firmware in [`../firmware/README.md`](../firmware/README.md).
>
> ✅ **2026-10-07: with the UART wire off, the TMC2209 moves the plunger.** *(Corrected: the
> wire that was off was EN, not UART. See the entry above.)* The board was
> cold with the wire on pin 9 and turned warm with it off. `tmc2209_probe.py` then proved the
> direction (DIR LOW is up), passed the rate ladder up to the ~8,700 steps/s `MOVE_TO` rate,
> and homed, matching the Tic's 09-29 numbers. So the board is fine, and the firmware's UART
> writes were what stopped it (wiring doc §25). Next is `pipette_test` with the wire off and
> `cubxl_run.py --no-tic`. Long term, either leave the wire off with pin 9 tied to a level, or
> flash `disableStealthChop()` and put the wire back. Record:
> [`tmc2209_probe_20261007`](../results/tmc2209_probe_20261007/README.md).
>
> 🔑 **2026-10-06: the board checks out, and the firmware may be what starves it.**
> Ben's meter readings on the TMC2209 were healthy: VM 12.4 V, VDD 5 V, VREF 0.586 V,
> coils 3.4 Ω, and DIAG 0 V once enabled. `tmc2209_probe.py` and the down-probe still saw
> no motion either way. The janelia library's `initialize()` switches off StealthChop's
> automatic current scaling, and `setupMotor()` never switches it back on. In that mode
> `IRUN 6` scales a fixed PWM amplitude, 36 × 7/32 of 256, instead of setting a regulated
> current. That works out to ≈0.1 A in the coils against the 1 A intended (wiring doc
> §24). Two tests are in
> [`tmc2209_probe_20261006`](../results/tmc2209_probe_20261006/README.md#next-two-ways-to-test-it):
> pull the UART wire (standalone mode), or flash `disableStealthChop()`.
>
> 🔴 **2026-10-05: the TMC2209 board was tried again, and it doesn't drive the
> plunger.** Ben swapped the Tic out for it. With the board plugged in, limit-switch
> probes sent 9 mm of moves in both directions, and none reached the switch. They
> started where the 10-02 run's last `HOME` left the plunger. Ben stood at the
> pipette for a 30 s buzz at 100 full steps/s and felt nothing. `CMD 29` read
> `comm = 0`. `pipette_test` was not run, and the pipette is going back on the Tic.
> The record and a checklist for another try are in
> [`tmc2209_probe_20261005`](../results/tmc2209_probe_20261005/README.md). If the
> TMC2209 goes back in, run its `tmc2209_probe.py` before any protocol, and give
> the runner `--no-tic`.
>
> ⚡ **2026-10-01: the trio runs in about 2 minutes, and there is a runner.** All
> three speed changes are in (CubOS status polling, F3000, fast `MOVE_TO`):
> 12/12 in 124 s against 238 s on 09-30, with no plunger steps lost (see
> [Speed](#speed)). Runs now go through one command,
> [`cubos/tools/cubxl_run.py`](../tools/cubxl_run.py), which checks, gates, runs
> and writes a one-screen `SUMMARY.md`; see [Running it](#running-it). The scale
> check below is still open.
>
> ✅ **2026-09-30: the pipette handles liquid.** Ben watched campaign 68 and
> reports that it aspirated (almost filling the tip below the foam filter),
> dispensed, and dropped the tip. That is the first end-to-end confirmation.
> Still open: the scale. Weigh one 20 µL dispense of water: about 20 mg means
> 796 steps/mm is right, about 10 mg means it is 1592. `UL_TO_MM 1.34` is also
> still Opentrons' nominal figure. The run took 4 minutes, and 73 s of that was
> the CubOS driver waiting on a serial timeout; see [Speed](#speed) below.
>
> 🔑 **2026-09-30 (b): the trio ran 12/12 on the Tic, and every plunger command
> executed.** `pick_up_tip`, `aspirate` (both legs, landing at 1.2 mm),
> `blowout` and both `drop_tip` legs all returned `OK` at their commanded
> rates, and a `HOME` after the run took 12.680 s against 12.687 s before it
> from the same position, so no steps were lost over ~160,000 in both
> directions. Not yet shown: liquid actually moving (needs eyes or a balance),
> and the 796 steps/mm scale (the ruler check). Before the run the GRBL
> controller was found **factory-reset** (`G54` zeroed, travel 400/300/100,
> soft limits off); the calibrated frame was restored from the 09-26 record.
> See [`pipette_test_20260930b`](../results/pipette_test_20260930b/README.md).
>
> **2026-09-30:** the Arduino now runs the same firmware with
> `STEPS_PER_MM 796` for the Tic's 1/8 step, so the warning below is resolved
> (796 cannot overshoot whichever scale is right; the ruler check is still
> open). The first trio with the Tic in circuit stopped in `decap vial_1` when
> all of the Pi's USB ports tripped over-current at once; see
> [`pipette_test_20260930`](../results/pipette_test_20260930/README.md).

**🔑 2026-09-29: the plunger moves.** A Pololu Tic T500 has replaced the condemned
Adafruit 6121. Driven through the Arduino, the plunger went up to the limit
switch, back down, and up to it again at every firmware rate, and the
firmware's `HOME` succeeded for the first time
([record](../results/pipette_switch_search_20260929/README.md)). ⚠️ **Don't
connect CubOS yet.** The firmware still has `STEPS_PER_MM 1592`, written for
1/16 step, and the Tic runs 1/8. So CubOS's connect-time `prime` would drive
about 56 mm, into the end of travel. Confirm 796/mm and flash it first
([Tic doc](./tic-t500-pipette-setup.md), steps 6–7).

*Until 2026-09-29 this read:* **The motion half works. The plunger has never
physically turned — the cable that caused it has been removed, and the driver
board it damaged is now condemned. Replace the Adafruit 6121.**

Every software and geometry problem between a protocol and the plunger is
solved and verified on hardware:

| | |
|---|---|
| tipped-pipette travel | **works** — the hover clamp lets `safe_z 115` coexist with a 35 mm tip on a machine whose Z tops out at 124 |
| `pick_up_tip` XY | **works** — commands the measured jog point to the millimetre, three runs running |
| `aspirate` / `blowout` / `drop_tip` | **execute**, reach the right planes, and the firmware emits the steps |
| volume conversion | **single conversion** — `mm_to_ul: 1.0` in CubOS, the calibration constant in the firmware |
| plunger retraction | **un-gated** — 14 mm of retraction ran at the commanded rate on the direct wiring, 2026-09-24 |
| firmware plunger planes | ✅ **P20 GEN2 image flashed and verified 2026-09-24** — prime 28.0 / blowout 32.5 / drop_tip 46.5, `UL_TO_MM` 1.34 |
| passive-instrument sweep | **0 interferences**, nominal and tip-stuck |
| the motor windings | ✅ **4.3 Ω / 3.7 Ω on direct wiring — healthy** |
| phase-to-phase isolation | ✅ **MΩ on direct wiring — the short left with the ribbon** |
| VREF at the trimmer wiper | ✅ **0.586 V ≈ 1.09 A peak — matched to `RUN_CURRENT_PERCENT 20`, so it no longer matters which one is in force** |
| the ribbon harness | 🔴 **condemned — it carried both the open coil path and the short** |
| **the Adafruit 6121 driver board** | 🔴 **condemned 2026-09-26 — `DIAG` survives a power-on reset *and* an `ENN` reset with a clean load. Replace it** |
| the TMC2209 UART readback | 🔴 **`comm = 0` with the read fix now live — the RX-side bridge resistor alone; move it during the swap** |
| the first bench move | ❓ **no movement seen — expected with the output stage off; re-run on the replacement** |
| **the plunger, on the Tic T500** | ✅ **moves both ways, 2026-09-29.** The limit switch opens after ~28.7 mm up, closes 2 mm down, and reopens after 2 mm at 200–2,500 microsteps/s. `HOME` works. Polarity correct. Tic left de-energized; `ticcmd --energize` before use |
| firmware `STEPS_PER_MM` | 🔴 **still 1592 (1/16 step) against the Tic's 1/8.** Confirm 796 by ruler or weight, then flash, before CubOS connects |
| the Pi | ✅ **back on the tailnet 2026-09-25 23:37 UTC, 5.13 V input, no under-voltage since boot** — ⚠️ keep its lead out of the gantry's reach (§21.7) |

Campaign 54 (2026-09-18) is the high-water mark: 12/12 steps, and for the first
time every plunger command — including the two retractions — emitted its steps
at the commanded rate with the LEDs corroborating the serial trace
command-for-command.

### What is eliminated, and what is left

```
  Arduino STEP/DIR output      PROVEN   1592 steps at the commanded rate
  polarity and timing          PROVEN   B/F LEDs match the trace, per command
  Arduino pin map              FIXED    Cubware's diagram is shifted one pin
  10-pin pipette header        VERIFIED across three sources; 180 deg flip excluded
  limit-switch gate            OPEN     retractions execute on the DIRECT wiring too
  VM at the screw terminal     13 V     measured 2026-09-17
  EN at the driver pin         0 V      candidate B ELIMINATED, 2026-09-21
  coil grouping in terminals   CORRECT  1A+1B = one winding, 2A+2B = the other
  serial link to the Pi        HEALTHY  10/10 clean round-trips
  motor windings               HEALTHY  4.3 / 3.7 Ohm once the ribbon is bypassed
  phase-to-phase isolation     HEALTHY  1A-2A and 1B-2B are megohms on direct wire
  the ribbon harness           FAULTY   it carried BOTH faults, and both left with it
  firmware aspirate planes     FIXED    GEN2 image flashed and verified 2026-09-24
  ------------------------------------- the whole coil side is now ruled out
  VREF at the trimmer wiper    0.586 V  the chip's 5 V regulator is alive
  DIAG pull-up                 NONE     0.5 MOhm; the schematic has nothing on DIAG
  outputs to GND / VM+         NO SHORT ~1.5 V in diode mode, all four alike
  header solder bridges        NONE
  ------------------------------------- everything outside the chip is ruled out
  ENN reset                    DONE     DIAG still high afterwards (4.2 V)
  power-on reset (2026-09-24)  DONE     DIAG still high afterwards (5 V)
  Adafruit 6121 / TMC2209      CONDEMNED  re-detects a fault on every enable
  UART readback              comm=0   read fix LIVE; only the RX-side bridge
                                      resistor is left. Move it during the swap.
```

On **2026-09-26** the last three outside causes came back clean — no pull-up on
`DIAG`, no output shorted to either rail, no solder bridges — and `DIAG` survived
the `ENN` reset, having already survived a power-on reset on 2026-09-24. The
TMC2209's short detection explains how that happens with nothing wrong outside:
it compares the voltage across each output MOSFET while it is switched on, so a
MOSFET or gate driver that no longer switches properly is, to the chip, a short
— re-detected about a microsecond after every enable, whatever is connected. A
meter from outside finds shorted MOSFETs, not weak ones. **The board is
condemned.** See §22 of the wiring doc, which pulls the TMC2209 datasheet and the
6121 schematic for the first time.

On **2026-09-23** Ben bypassed the 10-pin ribbon and its FC-10P and wired the
pipette straight to the driver's screw terminals. `1A`–`1B` read **4.3 Ω** and
`2A`–`2B` **3.7 Ω** — real stepper windings, and the first ever measured on this
machine. Every earlier reading of the same two pairs was kΩ to MΩ. Nothing about
the motor changed; only the harness left the path. **The motor is healthy and
the coil fault was in the ribbon, its crimps, the FC-10P, or the machine-end
solder junction.** See §18 of the wiring doc.

On **2026-09-24** the two cross pairs came back at **megohms** on the same
direct wiring. §17.2's `1A`–`2A` = 0 Ω was the other half of the fault, and it
has gone with the ribbon too. Two windings, correct resistance, properly
isolated — **the coil-side diagnosis is closed.** What that also does is make a
**damaged output stage the leading explanation for `DIAG`**: the ribbon
presented a phase-to-phase short at the driver's outputs, the pot had been at
full clockwise since 2026-09-17, and `EN` has been at 0 V, so the chip was
enabled and driving into that short across many sessions. That is a textbook way
to destroy a driver. See §19.

> ✅ **VREF is set: 0.586 V at the wiper (2026-09-26), ≈ 1.09 A peak.** Full
> clockwise on this board is ~1.5 A rms / 2.2 A peak — the trimmer is fed from
> `5VOUT` through 33 kΩ, so VREF tops out near 1.16 V, not the 2.5 V behind the
> "~3.3 A rms" quoted here until now (§22.5a). Still twice what a P20 GEN2 wants,
> so turning it down was right. Do not go below ~0.5 V: the datasheet calls that
> "not recommended" for current precision (§22.4).

### What to do next

> 🔴 **Changed 2026-09-26: replace the driver board.** The 2026-09-24 meter
> sequence is complete (§19.5 of the wiring doc, results in §22), and its last
> step's condition is met: `DIAG` still high after the `ENN` reset, with the coils
> connected and no rail short found — and it had already survived a power-on
> reset. Keep the old board, labelled; it is a known-bad reference.

> 🔀 **2026-09-29: if the replacement is a Pololu Tic T500** rather than another
> 6121, see [`tic-t500-pipette-setup.md`](./tic-t500-pipette-setup.md). It has the
> wiring diagram, the three Tic settings, the one firmware constant that changes
> (`STEPS_PER_MM` 1592 → 796) and the bring-up order. **Bring-up step 1 is
> done:** STEP/DIR, 1/8 step and 990 mA are in the Tic's memory and read back
> ([record](../results/tic_t500_settings_20260929/README.md)). **Steps 3 and 5
> were run later the same day:** wired and on 12 V, energized with no errors,
> coil current tracking the setting, and moves sent both through the Arduino and
> from the Tic itself. Whether the plunger turned is still to be confirmed by
> eye ([record](../results/tic_t500_first_moves_20260929/README.md)).
> ✅ **Confirmed at 18:05–18:10 by the limit switch,** which is the one sensor on
> the plunger. UP opened it after about 28.7 mm. DOWN 2 mm closed it, and UP
> reopened it after the same 2 mm at 200, 400, 800, 1,600 and 2,500
> microsteps/s. The firmware's `HOME` succeeded in 1.36 s
> ([record](../results/pipette_switch_search_20260929/README.md)). **Next:** step 6
> (confirm 796 microsteps/mm, by ruler or weight), then step 7 (flash it), and only
> then CubOS.

> ✅ **The deck is intact.** The 2026-09-24 trio was cut when the gantry
> travelled far enough from the outlet to unplug the Pi; Ben E-stopped it above
> vial 1 with the capper **not yet engaged**, so no cap was captured and nothing
> was dropped (§21.8). The position reference is still gone — recover with `$H`,
> never `$X` + a jog — and re-check `$20` before the next protocol run.

> ⛔ **The trio still does not validate, for two new reasons.** Ben
> recalibrated on the new bench (2026-09-26) and re-jogged the deck.
>
> - The gantry file now matches the controller: 391 / 236.665 / 124, `$20=1`.
> - The tip rack is converted from his A1 reading.
>
> What still fails:
>
> - The pipette cannot reach vial_1 at y 0.665. It sits +13 mm in Y from the
>   capper, which puts vial_1 12.3 mm past the Y limit.
> - Step 5's `travel_z: 87` is above the new `z_max: 121`.
>
> Fixing both gives PASS, 12/12, and 0 interferences. The options are in
> [`../results/pipette_test_20260926b/`](../results/pipette_test_20260926b/README.md).
> None of this touches the plunger work below, which needs no gantry motion.

> 🔴 **Keep the Pi's mains lead out of the gantry's reach.** Step 0 of every
> protocol drives to the far corner (now 391, 236.665), the extreme that pulled the plug
> on 2026-09-24. The Pi is back (2026-09-25 23:37 UTC, 5.13 V in, no
> under-voltage since boot), but whether the lead has been re-routed is not
> recorded. The durable fix is a supply of its own, ideally a small UPS (§21.7).

**Optional, before binning the old board** — neither changes the action (§22.7):

- **Holding torque.** Board powered, `EN` low, nothing commanded: gently push the
  plunger. Moves freely, as on 2026-09-17 ⇒ neither bridge is driving ⇒ bin it.
  Resists ⇒ say so before binning it.
- **Let the chip name its fault.** Do step 2 below first, then read `CMD 29`:
  `s2ga`/`s2gb`/`s2vsa`/`s2vsb`/`ot` name the failed bridge. It also proves the
  readback path on a board known to have flags, before the new board's "no
  flags" is trusted.

**Bringing up the replacement** (§22.8):

1. **Power off** — the 12 V *and* the Arduino's USB — whenever a motor or supply
   wire is touched. Same header wiring; same terminal colours (`1A` red, `1B`
   blue, `2A` green, `2B` black). Fit the 1515 heat sink now.
2. **Move the bridge resistor to the TX side**: `A1 —R— NODE`, with `A0` and
   `PDN_UART` directly on `NODE`. 1 kΩ is the library's recommendation; the
   10 kΩ already fitted works at 9600 baud. The GEN2 firmware carries the read
   fix, so `CMD 29` then reads the new chip from its first power-up.
3. **Strain-relieve the four bare motor leads.** A lead pulling out of its
   terminal under current is the textbook way to kill a stepper driver.
4. **First power-up with `EN` jumpered to 5 V**, so no coil current flows
   whatever the new trimmer is set to. Bring the 12 V up by switching the supply
   on, not by pushing a live lead into the terminal — the datasheet wants `VS`
   slopes below 1 V/µs or the charge-pump capacitor can pass destructive
   currents.
5. **Set VREF to 0.55–0.59 V** at the new trimmer's wiper.
6. 🔑 **Go/no-go: `DIAG` ≈ 0 V with `EN` at 5 V, and still ≈ 0 V after `EN` goes
   low.** The old board never passed this. 🔴 If `DIAG` jumps high the moment
   `EN` goes low, **power off and stop** — something external is tripping the
   new chip, and re-enabling into it is how the first one probably died.
7. **Holding torque** with `EN` low and nothing commanded — it should now resist.
8. **First motion: 1 mm down and back.** From the Pi,
   [`../tools/pipette_driver_measure.py`](../tools/pipette_driver_measure.py)
   `--move`; or from any laptop's Arduino Serial Monitor at 115200 baud with
   Newline endings, `16,1,1592,400` then `16,0,1592,400` — no CubOS, no Pi, no
   gantry (§22.9). Then 10 mm against a ruler: standalone `MS1`/`MS2` give 1/8
   stepping where the firmware assumes 1/16, so if the UART writes are not
   landing, a commanded millimetre travels two.
9. **Watch which way `HOME` seeks.** Direct wiring may have reversed a pair, and
   `homePipette()` seeks with `DIR` LOW. If the tip ejector starts to engage,
   the direction is inverted — swap the two wires of one pair.
10. **Rebuild or repair the harness before the pipette goes back on the
   gantry.** The ribbon was also the flexible tether. Solid wire into screw
   terminals will not survive gantry motion, and a terminal pulled out mid-run
   recreates exactly the open circuit that cost the last three weeks.

**Retired:** the terminal-block swap that §16.3 led with (§17.1); §17.5's
localisation sequence, which the substitution answered first; the whole
2026-09-24 meter sequence, now complete (§22.1); "cut both rails together",
because `VCC_IO` does not power the chip's logic and a `VM` cycle is a full reset
(§22.5c); `INDEX` during a driven leg, superseded by the verdict; and
reconnecting the limit switch, which reads clear on the direct wiring (§20.3).

### Queued behind the first real movement

- ✅ **The P20 GEN2 image is flashed and verified** (2026-09-24, §20.1), so
  `aspirate` descends to the P20's 28.0 rather than the P300's 36.0. Whether its
  `RUN_CURRENT_PERCENT 20` or the trimmer sets the coil current depends on
  whether the boot-time UART writes reach a powered chip; with VREF at 0.586 V
  the two agree, so it does not matter (§22.5b).
- **Check the first successful move against a ruler**, as in step 8 above. The
  firmware already contradicts itself about this: `STEPS_PER_MM 1592.0` against
  a homing back-off commented `796; // this is equal to 1mm`.
- **`UL_TO_MM` 1.34 is Opentrons' nominal figure**, not a calibration of this
  unit. It needs a gravimetric check, which is now possible: liquid moves as of
  2026-09-30.

## What is in this PR

| | |
|---|---|
| [`opentrons-pipette-wiring.md`](./opentrons-pipette-wiring.md) | the technical record: pin maps, the source inventory, every measurement, and two retracted hypotheses kept visible |
| [`pipette-thread/`](./pipette-thread/README.md) | the discussion from PR #171, migrated verbatim with links back |
| [`../firmware/`](../firmware/README.md) | the VCL PANDA build, the stock backup, both hex images, and the patch against upstream |
| `../patches/p20-gen2-plunger-constants.patch` | CubOS `p20_single_gen2` from Opentrons' own specs, replacing placeholders |
| `../patches/tmc2209-softwareserial-read.patch` | makes the janelia TMC2209 read path work on an AVR at all |
| `../patches/tipped-hover-clamp*.patch` | lets a tipped pipette travel on a machine whose ceiling is below `safe_z + tip` |
| `../patches/pipette-connect-tolerate-failed-home*.patch` | the escape hatch for an unreferenced plunger — **not a bug fix**, remove once homing works |
| `../patches/grbl-prompt-status-polling.patch` | the status-polling half of Alex's CubOS PR #351, backported to `496819c`; removes the 2 s wait after every G-code (see [Speed](#speed)). **Not applied to the Pi** |
| [`../tools/`](../tools/) | `pipette_driver_measure.py`, `pipette_driver_probe.py`, `pipette_bench_check.py`, `run_with_plunger_trace.py` |
| `../results/pipette_*` | 17 sessions of run logs, plunger traces, G-code, camera frames and `$$` dumps |

## Running it

CubOS lives on `rpi-5-des4` at `~/CubOS`; its install and patch state are in
[`SOP/raspberry-pi-cubos-setup.md`](https://github.com/vertical-cloud-lab/byu-vcl/blob/0561306/SOP/raspberry-pi-cubos-setup.md),
which is on [#171](https://github.com/vertical-cloud-lab/byu-vcl/pull/171) and not in this PR.

### With the runner (since 2026-10-01)

This branch is checked out on the Pi as a worktree at `~/byu-vcl-pipette`
(`~/byu-vcl` itself stays on #171's branch). One command does the whole routine
and writes one folder:

```bash
git -C ~/byu-vcl-pipette pull --ff-only          # run the committed configs
setsid nohup ~/CubOS/.venv/bin/python ~/byu-vcl-pipette/cubos/tools/cubxl_run.py \
    --name pipette_test_YYYYMMDD > /tmp/cubxl_run.out 2>&1 < /dev/null &
cat ~/cubxl_runs/pipette_test_YYYYMMDD/SUMMARY.md   # when done
```

Results go to `~/cubxl_runs/<name>/`, outside the checkout so the `pull` never
conflicts; copy the folder into `cubos/results/` to commit it.

[`cubos/tools/cubxl_run.py`](../tools/cubxl_run.py) defaults to the trio below.
In order, and any refusal before the run means nothing moved:

1. **checks**: commits and which `cubos/patches` are applied; ports present, not
   held open, and named identically where shared; protocol step 0 is `home`
   (opening the GRBL port resets it, so anything else would move against a lost
   position); `$$` against the gantry file, `G54 == -max_travel` (catches a
   factory reset), feed within `$110`–`$112`; the Arduino answers and nothing is
   on the magnet; the Tic's settings equal [`tic_p20.txt`](tic_p20.txt), then
   it is energized. Protocols with a `breakpoint` are refused, because the run
   is headless.
2. **gates**: `validate_setup`, `run_protocol --mock`, `passive_shadow` nominal and
   `--tip-stuck`.
3. **run**: `run_with_camera_and_plunger_trace.py`, with the Tic polled and the
   GRBL logs sliced to the run.
4. **post-run**: magnet off, cap sensor, plunger `STATUS`; with `--home-check`, a
   plunger `HOME` whose duration says whether any steps were lost; Tic
   de-energized.
5. **summary**: `SUMMARY.md` (one screen) and `summary.json`; `--baseline <dir>`
   adds a comparison.

`--checks-only` stops after stage 2 (about 25 s, no motion). `setsid nohup` is
only so an SSH drop can't take the run with it; the runner also ignores SIGHUP.
Exit status 0 = completed, 1 = ran and failed, 2 = refused, 3 = runner error.

### By hand

Run from a foreground SSH session if the protocol has a `breakpoint` — a headless
run logs *"Breakpoint skipped because stdin is not interactive"* and continues.

```bash
C=~/byu-vcl-pipette/cubos/configs; PY=~/CubOS/.venv/bin/python
G=$C/gantry/cub_xl_ben_pipette_capper.yaml
D=$C/deck/ben_6vials_tiprack.yaml
P=$C/protocol/vcl/pipette_test.yaml

$PY -m cubos.tools.validate_setup      $G $D $P      # nothing moves
$PY -m cubos.tools.run_protocol --mock $G $D $P
$PY ~/byu-vcl-pipette/cubos/tools/passive_shadow.py $G $D $P --tip-stuck
$PY ~/byu-vcl-pipette/cubos/tools/run_with_plunger_trace.py  $G $D $P   # the real run, timed
```

Four gates pass offline and none of them models the *other* instrument on the
head, which is what `passive_shadow.py` is for. Re-home before every run: the
GRBL board resets when the port opens and comes up in `Alarm`.

## Speed

Measured from campaign 68 (2026-09-30), the 12-step trio: **238 s** from gantry
connect to disconnect ([logs](../results/pipette_test_20260930b/README.md)).

| part | time | waiting, not moving |
|---|---|---|
| 47 gantry moves (`G01`, one axis each) | 127.5 s | ~58 s; the moves themselves need ~69 s at F2000 |
| 2 homing cycles | 38.2 s | ~11 s, after the opening `$H` |
| 8 plunger commands (incl. connect) | 45.7 s | none; `MOVE_TO` runs at ~2,400 steps/s |
| connect, cameras, capper dwell, disconnect | ~27 s | ~4 s (`G90` and `F3000` at connect) |

**Every gantry command took a multiple of ~2.06 s, including 1 mm moves.** In
CubOS `496819c`, `Mill.current_status()` reads the port *before* sending `?`.
GRBL sends nothing unprompted (`$10=0`), so that read waits out the serial
timeout: 2 s normally, 10 s during `home`. Alex's CubOS
[PR #351](https://github.com/Ursa-Laboratories/CubOS/pull/351) (draft, not
merged) sends `?` first. Its `current_status()` hunk and its six tests are
backported here as `../patches/grbl-prompt-status-polling.patch`. Offline on the
Pi's exact tree (`496819c` + the three applied patches), the six tests fail
without it and pass with it, and the whole core suite passes (2550, 0 failed). A
real-time fake GRBL reproduces the log: a 1.5 s move returns after 2.05 s today
and 1.55 s patched. Nothing has been tested on hardware yet, here or upstream.
The G-code and feed rates are unchanged.

The levers, per run, measured against this log:

| change | saves | notes |
|---|---|---|
| apply `grbl-prompt-status-polling.patch` | ~70 s | same G-code; only the waiting goes |
| delete `default_feed_rate_mm_min: 2000.0` (CubOS default 3000; GRBL allows 5000) | ~19 s, with or without the patch | each move still ramps down to a stop at its target |
| firmware `MOVEMENT_VELOCITY` 2500 → 10000, keeping moves into the ejector zone (target > `BLOWOUT_POSITION`) at 2500 | ~25 s | 10000 hits the firmware's 100 µs step-delay floor, ~8,700 steps/s. That is the rate `ASPIRATE` already runs at, because CubOS sends speed 0 and `aspirate()` passes it through. It is ~11 mm/s, about Opentrons' 7.56 µL/s P20 GEN2 default flow. Opentrons ejects tips at 15 mm/s |
| end the protocol parked instead of homed | ~15 s | the closing `home` is the move to the far corner that pulled the Pi's cable on 09-24 |
| coordinated XY diagonals (the other half of PR #351) | ~5–10 s | depends on upstream's routing stack; wait for it to merge |

The first three together take a run from about 4 minutes to about 2.

**Measured 2026-10-01, all three applied** (campaign 75,
[`../results/pipette_test_20261001/`](../results/pipette_test_20261001/SUMMARY.md)):
the same 12 steps, same configs otherwise, 12/12.

| | campaign 68 (09-30) | **campaign 75 (10-01)** | saved |
|---|---:|---:|---:|
| whole run | 238 s, connect to disconnect | **124 s**, process start to end | 114 s |
| 47 `G01` moves | 127.5 s | **55.2 s** (median 0.91 s; 1 mm moves now 0.06 s) | 72 s |
| 2 `$H` cycles | 38.2 s | **28.6 s** (7.9 + 20.7) | 10 s |
| 8 plunger commands | 45.7 s | **20.3 s** | 25 s |

The prediction above was 70 + 19 + 25 = 114 s; the measurement is 114 s. The
ejector push (`MOVE_TO 46.5`) took 4.65 s on both days, as intended. **No
plunger steps were lost at the faster rate:** a plunger `HOME` after the run,
from the firmware's 28.0 mm, took 12.677 s against 12.680 s on 09-30, i.e.
27.99 mm (−0.01 mm). The Tic logged no errors (VIN 9.0–11.3 V), and the kernel
logged no USB events.

## Things that cost a session each, so they are worth reading twice

- **`WPos` is GRBL's step counter, not a measurement.** With the stepper supply
  off the controller accepts every `G01`, emits the steps, and reports a
  plausible position while the machine stands still. `Pn:` is driven by the limit
  switches and *is* power-independent — that is the discriminator.
- **A round trip that scales with distance only proves the Arduino toggled STEP.**
  `stepMotor()` bit-bangs the pin and counts loop iterations; there is no
  encoder, no current sense, no feedback of any kind.
- **`offline: true` on an instrument does not mean "not attached."** It stubs the
  instrument into a simulator that agrees with itself while the gantry keeps
  moving for real. That is how a capper came to press onto six still-capped vials.
- **`validate_setup` asks whether a coordinate is reachable, never whether it is
  the right one.** A tip-rack anchor 52 mm out passes it.
- **A test whose negative result is already predicted is not a test.** The first
  bench move was run with `DIAG` asserted — which disables the output bridges by
  definition — *and* with the VREF pot freshly turned down to an unrecorded
  value. It showed nothing, as it had to, and the risk was that "no movement"
  got read as "the board is dead" (§21). Before spending hardware time, ask what
  each outcome of the test would rule out; if one of them rules out nothing, fix
  the ordering first.
- **The Pi is the host, so losing its power loses the evidence.** The run log,
  the plunger trace and the camera frames are all written on the Pi, and the
  closing `home` and `CMD_EMAG_OFF` are commands *from* it. A gantry that can
  reach the Pi's mains lead is therefore a data-integrity and machine-state
  problem, not just an interrupted run (§21.7).
- **A clean short test from outside does not clear a driver.** The TMC2209
  detects a short by the voltage across a MOSFET it has switched on, so a MOSFET
  or gate driver that no longer switches properly *is* a short as far as the chip
  is concerned — re-detected a microsecond after every enable, whatever is
  connected. A meter finds shorted MOSFETs, not weak ones (§22.2).
- **Read the schematic and the datasheet before quoting a limit.** "~3.3 A rms
  full scale" was repeated for a week on the assumption that the trimmer could
  reach 2.5 V; the 6121 feeds it through 33 kΩ and it tops out near 1.16 V
  (§22.5a). Both documents were a download away the whole time.

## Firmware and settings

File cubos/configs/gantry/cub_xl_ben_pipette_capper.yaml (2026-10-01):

# cub_xl_ben_pipette_capper.yaml -- CubXL, @benwhitney5463's 2026-09-26 rev:
# the gantry recalibrated on its new bench.
#
# Attached to PR #228 on 2026-09-26. THE BODY BELOW IS BEN'S, VERBATIM (parsed
# YAML verified identical to the attachment). A cnc.default_feed_rate_mm_min:
# 2000.0 line was added back on 2026-09-26 and removed again on 2026-10-01, at
# Ben's request, as speed change 2 (below).
#
# It matches the controller. Read-only from the Pi, 2026-09-26 01:17 UTC, eight
# minutes after the GRBL board came back onto the Pi's USB at 01:09:56 UTC. It
# had been off the Pi since 00:53:37, the window this calibration fits:
#   $130 / $131 / $132   391.000 / 236.665 / 124.000
#   G54                  -391.000, -236.665, -124.000
#   $3=1 $10=0 $20=1 $22=1 $23=0 $27=3 $100-$102=400   every critical value
# so CubOS's connect-time settings check passes. Snapshot in
# ../../results/pipette_test_20260926b/grbl_settings_20260926b.json.
#
# Changes vs. the previous committed rev (2026-09-15; 409 / 309 / 124):
#   grbl max_travel x / y / z        409 / 309 / 124  ->  391 / 236.665 / 124
#   working_volume x / y / z max     386.333 / 232 / 124  ->  388 / 233.665 / 121
#                                    (= max_travel minus the 3 mm pull-off, i.e.
#                                    the homed pose: no move ends on a limit
#                                    switch now, as the 124 hover used to on Z)
#   capper depth                     -15.935  ->  -17.0
#   pipette offset_x / offset_y      52.0 / 12.0  ->  54.0 / 12.999
#   capper park_position             deleted 2026-09-15  ->  [236, 25] again
#   cnc.default_feed_rate_mm_min     2000.0  ->  absent  (kept at 2000.0 until
#                                    2026-10-01, then removed: see below)
#
# ---------------------------------------------------------------------------
# default_feed_rate_mm_min: absent, so CubOS's 3000 mm/min (2026-10-01)
# ---------------------------------------------------------------------------
# Ben's file never had it; it descends from his own local copy (it has
# park_position, which the branch deleted on 2026-09-15). It was added back at
# 2000.0 on 2026-09-26 because every run on this machine to that date used F2000,
# and removed on 2026-10-01 as speed change 2 of
# ../../docs/pipette-setup-and-troubleshooting.md#speed. Absent, CubOS 496819c
# sends every G01 at its module default DEFAULT_FEED_RATE = 3000 mm/min
# (gantry_driver/driver.py). The controller allows it: $110-$112 = 5000 mm/min,
# $120-$122 = 300 mm/s^2, read 2026-09-30.
#
# ---------------------------------------------------------------------------
# park_position: harmless, kept as sent
# ---------------------------------------------------------------------------
# CubOS 496819c ignores it and warns on every load: "YAML field 'park_position'
# is no longer used and was ignored (decap/cap no longer park; delete this
# key)." It is also what a rollback to cbc33dc would need back.
#
# ---------------------------------------------------------------------------
# z_max 121 lowers the tipped ceiling by 3 mm
# ---------------------------------------------------------------------------
# safe_z 115 still needs the hover-clamp patch (applied on the Pi): a tipped
# engage cannot reach safe_z, so it hovers at the highest carriage-reachable
# plane, now gantry 121 = tip end at deck 86 (was 124 / 89). Cap tops are at
# deck 54 + 15 = 69, so that is 17 mm of clearance. The clamp does NOT touch an
# explicit travel_z, which must now be <= 121 - 35 = 86 whenever it names the
# tipped pipette. pipette_test.yaml's step 5 still says 87 and fails
# validation on it: gantry z 122 > z_max 121.
#
# ---------------------------------------------------------------------------
# The pipette's reach
# ---------------------------------------------------------------------------
# CubOS commands gantry = deck - offset, so with offset (54.0, 12.999) the
# pipette cannot reach below deck x 54.0 or deck y 12.999 (gantry 0). The
# capper (offset 0/0) can. See the deck file's header for what that means for
# vial_1.

serial_port: /dev/ttyUSB0
gantry_type: cub_xl
cnc:
  factory_z_travel_mm: 124.0
  calibration_block_height_mm: 35.0
  y_axis_motion: head
  safe_z: 115.0
working_volume:
  x_min: 0.0
  x_max: 388.0
  y_min: 0.0
  y_max: 233.665
  z_min: 0.0
  z_max: 121.0
origin_policy: deck_origin
grbl_settings:
  dir_invert_mask: 1
  status_report: 0
  soft_limits: true
  homing_enable: true
  homing_dir_mask: 0
  homing_pull_off: 3.0
  steps_per_mm_x: 400.0
  steps_per_mm_y: 400.0
  steps_per_mm_z: 400.0
  max_travel_x: 391.0
  max_travel_y: 236.665
  max_travel_z: 124.0
instruments:
  vial_capper_decapper:
    type: capper
    vendor: pawduino
    offset_x: 0.0
    offset_y: 0.0
    depth: -17.0
    capture_retries: 2
    capture_settle_s: 1
    engage_depth_mm: 15
    offline: false
    park_position:
    - 236
    - 25
    port: /dev/ttyACM0
  pipette:
    type: pipette
    vendor: opentrons
    offset_x: 54.0
    offset_y: 12.999
    depth: 0.0
    pipette_model: p20_single_gen2
    port: /dev/ttyACM0
    offline: false

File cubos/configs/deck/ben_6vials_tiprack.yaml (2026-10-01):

# ben_6vials_tiprack.yaml -- @benwhitney5463's vial column plus the 2x15 tip
# rack, CubXL.
#
# 2026-09-30: vial_1 y 0.665 -> 33.665 and vial_2 y 33 -> 66. Ben moved both
# vials +33 mm in Y so the pipette can reach vial_1 (its lowest reachable deck
# Y is 12.999). aspirate vial_1 now commands gantry (135.0, 20.666, 54.0).
# validate_setup PASS, mock 12/12, passive_shadow 0 / 0. The "vial_1 is outside
# the PIPETTE's reach" section below is history. Record:
# ../../results/pipette_test_20260930/README.md
#
# --- the 2026-09-26 header, unchanged below ---
# ben_6vials_tiprack.yaml -- @benwhitney5463's vial column plus the 2x15 tip
# rack, CubXL, 2026-09-26 rev: the new bench, in the new calibration's frame
# (391 / 236.665 / 124; see the gantry file).
#
# Attached to PR #228 on 2026-09-26. THE BODY BELOW IS BEN'S, VERBATIM (parsed
# YAML verified identical to the attachment) EXCEPT the tip rack's XY, which
# Ben asked to be set from a new jog reading:
#   "I measured these coordinates with the pipette tip hovering over the a1
#    spot: x= 265.0 y = 32.665."
#
# Changes vs. the previous committed rev (2026-09-01, old frame):
#   vial_3 .. vial_6            removed (pipette_test.yaml only uses 1 and 2)
#   vial_1 location             (206, 27, 55)   ->  (189, 0.665, 54)
#   vial_2 location             (206, 60, 55)   ->  (189, 33, 54)
#   tip_rack calibration.a1     (336, 37.5)     ->  (319.0, 45.664)   converted
#   tip_rack calibration.a2     (327.5, 37.5)   ->  (310.5, 45.664)
#   tip_rack location x / y     (336.5, 37.5)   ->  (319.5, 45.664)
#   pickup_z 57, drop_z null, tip_length 35, everything else   unchanged
#
# ---------------------------------------------------------------------------
# The tip-rack anchor: the jog reading plus the NEW pipette offset
# ---------------------------------------------------------------------------
# The jog display shows raw WPos, which is the capper's frame (offset 0/0).
# CubOS commands gantry = deck - instrument offset, so a point read with the
# PIPETTE over it sits in the deck frame at reading + pipette offset. The
# offset is the 2026-09-26 one, (54.0, 12.999), not the old (52, 12):
#   a1 = (265.0 + 54.0, 32.665 + 12.999) = (319.0, 45.664)
# a2 is one 8.5 mm column step in -X of a1, as in every rev since 2026-08-24;
# rows advance +Y, so A1..O1 run deck y 45.664..164.664 (gantry 32.665..151.665,
# all inside the working volume). location keeps Ben's +0.5 mm X from a1.
#
# Checked through the CubOS loader, not asserted. pick_up_tip tip_rack.A1:
#   Moving OpentronsPipette to (319.000, 45.664, 57.000)
#                           -> gantry (265.000, 32.665, 57.000)
# which is the measured jog point exactly. The XY of the pickup reproduces the
# reading whatever the offset is; the offset only matters for points measured
# with the capper and visited by the pipette, i.e. the vials.
#
# ---------------------------------------------------------------------------
# vial_1 is outside the PIPETTE's reach (the capper reaches it fine)
# ---------------------------------------------------------------------------
# The pipette sits +12.999 mm in Y from the capper, so the lowest deck Y it can
# reach is 12.999 (gantry y 0). vial_1 at y 0.665 would need gantry y -12.334:
#   pipette -> vial_1.location.action_z: gantry (135.0, -12.334, 54.0)
#   violates y_min=0.0
# so validate_setup FAILS pipette_test.yaml's `aspirate: vial_1`. vial_2
# (gantry y 20.001) is fine. The fix is physical or a protocol choice, not a
# number here: see ../../results/pipette_test_20260926b/README.md, section 3.
#
# ---------------------------------------------------------------------------
# pickup_z 57: unverified in this frame
# ---------------------------------------------------------------------------
# No Z came with the new reading. pick_up_tip is a friction press with no
# sensor, so a miss is silent; jog the nozzle down onto A1 once and read Z.
#
# drop_z: null is still right. drop_z is only a bounding-box height at this
# CubOS version (tip_rack.py: max(abs(pickup_z - drop_z), 1.0)), never a motion
# target. drop_tip engages the TIP END to the rack's z 57 = gantry 92, a full tip
# length above the slot; the real fix is a `tip_disposal` deck entry.
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

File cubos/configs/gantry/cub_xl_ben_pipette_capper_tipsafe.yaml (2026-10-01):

# cub_xl_ben_pipette_capper_tipsafe.yaml -- the CubXL gantry config that
# pipette_test.yaml (2026-08-28 revision) is verified against.
#
# This is @benwhitney5463's 2026-08-28 attachment with TWO values changed,
# both marked CHANGED inline. It exists as a separate file rather than an
# edit to cub_xl_ben_pipette_capper.yaml because it is only correct TOGETHER
# WITH a CubOS patch that is not applied to the Pi by default:
#
#   cubos/patches/tipped-hover-clamp-and-ceiling-travel.patch
#   cd ~/CubOS && git apply ~/byu-vcl/cubos/patches/tipped-hover-clamp-and-ceiling-travel.patch
#   (reverse with `git apply -R` -- it is a working-tree patch, not a commit)
#
# WITHOUT THE PATCH THIS FILE IS WORSE THAN THE ORIGINAL: safe_z 122 makes
# every tipped pipette engage (aspirate/blowout/mix/drop_tip) ask for gantry
# 122 + 35 = 157, and validate_setup rejects it. Use the unmodified
# cub_xl_ben_pipette_capper.yaml on an unpatched CubOS, and then only for
# protocols that never touch the capper while a tip is attached.
#
# THE PROBLEM THIS SOLVES
#   safe_z is one number shared by both tools and applied at each tool's own
#   point. A 35 mm tip puts the pipette's tool point 50.935 mm below the
#   capper's (35 + the capper's depth -15.935). So:
#       tipped pipette hover needs   safe_z <= z_max - 35        = 87
#       capper legs clear cap tops   safe_z >= 68 + 50.935       = 119
#   A protocol that pipettes AND caps with the tip on needs both. The window
#   is empty by 32 mm, and safe_z is additionally hard-capped at z_max, so no
#   value of safe_z can satisfy it. The patch breaks the coupling: the tipped
#   hover clamps to the highest carriage-reachable plane instead of tracking
#   safe_z, and XY travel rides the working-volume ceiling so the passive
#   tool clears the deck.
#
# VERIFIED 2026-08-28 against CubOS cbc33dc + all three local patches:
#   validate_setup            PASS (19 targets, 19 steps)
#   run_protocol --mock       19/19
#   passive_shadow            0 interferences
#   passive_shadow --tip-stuck 0 interferences
# Logs in cubos/results/pipette_test_20260828/.
#
# NOT verified on hardware: no run has been made with this file. The Pi was
# off the tailnet (last seen 2026-08-28 00:26 UTC) for the whole session.
serial_port: /dev/ttyUSB0
gantry_type: cub_xl
cnc:
  factory_z_travel_mm: 129.0
  calibration_block_height_mm: 35.0
  y_axis_motion: head
  # CHANGED (was 87.0). Only valid with tipped-hover-clamp-and-ceiling-travel
  # applied; see the header. 87.0 was the only value that let a tipped
  # aspirate/blowout validate on stock CubOS, because those commands hover at
  # safe_z measured AT THE TOOL POINT (87 + 35 = 122 = z_max exactly). The
  # cost was that every capper leg then travelled at gantry 87 - 15.935 =
  # 71.065, carrying an attached tip's end at deck 36.065 -- 32 mm below the
  # cap tops and 19 mm below the rims. With the patch the tipped hover no
  # longer tracks safe_z, so safe_z is free to serve the capper: 122 puts
  # capper transits at the ceiling (tip end at deck 87, 19 mm over the caps)
  # while a tipped engage still clamps to gantry 122.
  safe_z: 122.0
working_volume:
  x_min: 0.0
  x_max: 386.333
  y_min: 0.0
  y_max: 232.0
  z_min: 0.0
  z_max: 122.0
origin_policy: deck_origin
grbl_settings:
  dir_invert_mask: 1
  status_report: 0
  soft_limits: true
  homing_enable: true
  homing_dir_mask: 0
  homing_pull_off: 3.0
  steps_per_mm_x: 400.0
  steps_per_mm_y: 400.0
  steps_per_mm_z: 400.0
  max_travel_x: 389.333
  max_travel_y: 235.0
  max_travel_z: 125.0
instruments:
  vial_capper_decapper:
    type: capper
    vendor: pawduino
    offset_x: 0.0
    offset_y: 0.0
    depth: -15.935
    capture_retries: 2
    capture_settle_s: 1
    engage_depth_mm: 13
    offline: false
    # CHANGED (was [125, 50]). Every decap/cap ends with a raw move to this
    # point at safe_z -- a raw move, so it does NOT get the patch's ceiling
    # travel and rides at gantry safe_z - 15.935 = 106.065. Off the vial
    # column, that leg translates X across the column with the passive
    # nozzle at deck Z 106.065 (tip end 71.065, ~3 mm over the caps).
    # [206, 50] is the vial column's own X, which makes every capper leg a
    # pure-Y move holding the passive nozzle at deck X 258 -- 38 mm clear of
    # the vials (edge at 220) and 22 mm clear of the tip rack body (~280).
    # Nothing crosses anything, so the 3 mm never matters.
    # STILL NOT A MEASURED CAP-STAGING COORDINATE -- it is a safe transit
    # point, and no cap is ever set down there by this protocol.
    park_position:
    - 206
    - 50
    port: /dev/ttyACM0
  pipette:
    type: pipette
    vendor: opentrons
    offset_x: 52.0
    offset_y: 12.0
    depth: 0.0
    pipette_model: p20_single_gen2
    port: /dev/ttyACM0
    offline: false

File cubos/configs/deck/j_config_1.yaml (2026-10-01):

# Jarrett's 6-vial deck ("j_config_1"), measured 2026-08-06/07 with the
# multi-instrument-calibrated gantry (capper = reference instrument, i.e.
# offset 0/0). Attached by @jarrettshupe to PR #171 on 2026-08-08; the six
# vial entries below are byte-identical to that attachment.
#
# COORDINATE SEMANTICS (differs from sterling_6vials.yaml!): every vial's
# location.z is NOT the rim -- it is the raw jog-widget work coordinate
# (WPos) at which the capper_decapper engages the cap ("the z coordinate
# where the capper_decapper should be engaging with the vial caps"). The
# Operator UI's position widget displays raw WPos with no instrument offset
# or depth applied (GantryPositionWidget shows work_x/y/z, .toFixed(3) --
# hence the 3-decimal values). The gantry config pairs with this via
# engage_depth_mm: 17.248 = -capper.depth, which makes CubOS's commanded
# engage gantry Z equal location.z exactly. Do NOT reuse these z values as
# rim heights: the rim is ~4.25 mm ABOVE location.z in WPos terms (from the
# 2026-08-03 hardware-verified sterling numbers: rim 55.0, engage 50.75).
#
# NOTE the key/name offset: deck KEYS are vial_2..vial_7 (protocol targets
# resolve by key), while the display `name:` fields say vial_1..vial_6.
# So `decap: vial: vial_2` opens the physical vial labeled "vial 1".
#
# ONE ADDITION vs. the attachment: the `tip_rack` entry at the bottom.
# The measured tip position (262.460, 32.792, 59.152) was taken with the
# pipette pressed onto the tip but read from the SAME raw-WPos widget, so
# it is a gantry coordinate, not a pipette deck target. CubOS converts a
# pipette deck target to gantry via gantry = deck - offset (XY) and
# gantry_z = deck_z + depth (pipette depth 0), so the deck-frame numbers
# entered here are WPos + pipette offset (51.97, 12.0), Z unchanged:
#   x = 262.460 + 51.97 = 314.430
#   y =  32.792 + 12.00 =  44.792
#   z =  59.152 (pipette depth 0.0 -> deck Z == WPos Z)
# Modeled as a 1x1 rack holding the single tip A1; tip_length 35.0 is from
# the 2026-08-06 request ("the pipette tip adds 35mm to the pipette").
# calibration.a2 only fixes the row orientation required by the schema.

labware:
  vial_2:
    type: vial
    name: vial_1
    model_name: ''
    height: 83
    diameter: 28
    location:
      x: 212.143
      y: 106.365
      z: 54.7
    capacity_ul: 1500
    working_volume_ul: 1200
  vial_3:
    type: vial
    name: vial_2
    model_name: ''
    height: 83
    diameter: 28
    location:
      x: 212.143
      y: 137.615
      z: 54.295
    capacity_ul: 1500
    working_volume_ul: 1200
  vial_4:
    type: vial
    name: vial_3
    model_name: ''
    height: 83
    diameter: 28
    location:
      x: 212.143
      y: 172.28
      z: 54.295
    capacity_ul: 1500
    working_volume_ul: 1200
  vial_5:
    type: vial
    name: vial_4
    model_name: ''
    height: 83
    diameter: 28
    location:
      x: 212.143
      y: 203.948
      z: 54.295
    capacity_ul: 1500
    working_volume_ul: 1200
  vial_6:
    type: vial
    name: vial_5
    model_name: ''
    height: 83
    diameter: 28
    location:
      x: 212.143
      y: 238.005
      z: 54.295
    capacity_ul: 1500
    working_volume_ul: 1200
  vial_7:
    type: vial
    name: vial_6
    model_name: ''
    height: 83
    diameter: 28
    location:
      x: 212.143
      y: 271.013
      z: 54.295
    capacity_ul: 1500
    working_volume_ul: 1200
  # Single-tip "rack" -- see the header for the frame conversion from the
  # measured (262.460, 32.792, 59.152) WPos reading.
  tip_rack:
    type: tip_rack
    name: tip_rack
    rows: 1
    columns: 1
    pickup_z: 59.152
    tip_length: 35.0
    x_offset: 10.0
    y_offset: 10.0
    calibration:
      a1:
        x: 314.43
        y: 44.792
        z: 59.152
      a2:
        x: 324.43
        y: 44.792
        z: 59.152

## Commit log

2026-04-10 Add Pico W MicroPython troubleshooting guide for SSL and USB issues
    Agent-Logs-Url: https://github.com/vertical-cloud-lab/byu-vcl/sessions/5f016d21-2d33-497d-8f2f-68681795fec1
2026-04-10 Revert "Add Pico W MicroPython troubleshooting guide (SSL error + USB connection fixes)"
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2026-07-01 Revise TMS 2027 abstract for poster submission per Edison feedback
    - Target symposium confirmed: AI-Enabled Materials Processing (flyer 021),
    with AI/ML/Data Informatics (flyer 022) as alternate
    - Reframe novelty as open, low-cost, many-camera, multi-site livestreaming
    infrastructure for SDL operations
    - Add >99% uptime, tunable frame rate/resolution, failsafe auto-restart
    - Reword full provenance to visual audit trail linked to timestamps and
    experiment metadata
    - Apply Edison top suggestions: positioning vs task-specific CV, black-box/
    provenance and democratized-SDL framing, privacy-by-design, materials-
    specific examples for TMS audience
    - Scope utilization as heuristic and rob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
2026-07-06 docs: consolidate pipette survey + incorporate issue #149 findings
    Fold @benwhitney5463's two-category request from issue #149 into the CubXL
    pipette write-up on this PR branch: Category 1 (cheaper OT-2-style OEM
    modules/pumps) and Category 2 (open-source designs with tip replacement).
    Adds TriContinent Air-Z / AccuPump2 / BasePump, Tecan Cavro, the North
    Robotics press-fit-tip + passive-stripper strategy, OTTO repo, the ~$4-5
    3D-printable ISO-8655 head, HYKYHT, real Opentrons/LabX pricing, and a
    tip-replacement/cross-contamination approaches section.
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2026-09-03 Document HF Spaces, YouTube wiring, and the RP2040 I2C regression
    Spaces: byu-vcl/OT-2-LCM and byu-vcl/light-mixing, both private on
    cpu-basic, duplicated from the Acceleration Consortium originals. Their
    secrets live in the Space's own settings rather than GitHub, so the two
    have to be kept in sync by hand. Three edits were needed on top of the
    duplicate and will need re-applying if they are ever re-duplicated: the
    device IDs were hardcoded to the AC's own hardware; DB_utils.py opened
    every collection on LCM-OT-2-SLD, which our database user has no rights
    to, so every write would have failed authorization; and the YouTube
    lookup ran at import time behind a raise_for_status(), meaning a miss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
2026-09-11 Add two Opentrons App protocols: dock pick-up from both sides, and read height
    Protocols only, for running from the Opentrons App -- no liquid handling and no
    change to run_xscan_test.py.
    - 01_pickup_both_sides.py -- hover over each socket of the charging base, pick
    up in place, or shuttle the enclosure A1 -> A2 -> A1. The hover mode exists
    because Labware Position Check stores ONE offset per labware and so slides
    both sockets together: an error common to both is LPC's job, an error on one
    socket has to be fixed in the definition. Hovering over both in one run is
    what tells those two cases apart.
    - 02_read_height_over_well.py -- carry the enclosure to one well of a 96-well
    plate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
2026-09-12 Document who has got accurate colour results before, and how
    Asked on #197 whether anyone on this project has ever obtained accurate colour
    results, and for the full list of steps taken to ensure accuracy. Research
    only -- no hardware, no robot motion, no behaviour changed.
    Answer: yes, twice, both upstream at the Acceleration Consortium; never yet in
    this repo. The quantified one is Yanghuang Lin's per-well white reference
    (Feb 2025), which took repeatability from 6-7% RSD to 1.2-2.3% and carried a
    whole MSE403H1 practical. The second is Kelvin Chow's March 2026 recovery --
    light panel under the plate, curtains, per-well blank normalisation -- which
    started from the identical failure this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
2026-09-12 Document the OT-2 calibration procedure and report what is actually missing
    Asked on #197 what the ac_6_tuberack_15000ul.json file was, and for calibration
    instructions rather than only import instructions. Documentation plus one
    read-only helper -- no robot motion, nothing sent to the sensor.
    The tube rack is the paint stock reservoir: six positions for 15 mL tubes
    (20 mm bore, 58 mm deep), slot 3 in the AC protocol, from which the P300
    aspirates R/Y/B out of B1/B2/B3. Not a measurement target, and not needed at
    all if the paint is pipetted in by hand.
    The 96-well plate needs no import. corning_96_wellplate_360ul_flat is a stock
    Opentrons definition loaded with plain load_labware. Only th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
2026-09-12 Point the consolidated calibration docs at the dock definition in protocols/
    The calibration work and the Opentrons App protocols were written on separate
    branches, so `calibration_status.py --labware ac_color_sensor_charging_port.json`
    named a file that only exists now that both are on one branch -- and it lives in
    `protocols/`, not beside the script. Fixed in the script's usage line and in the
    README, and `opentrons-calibration.md` step 4 now points at the committed copy
    rather than only at the upstream AC repo, since the app's Import screen needs a
    standalone .json and cannot read the copies embedded in the protocol files.
    Refs #197, #33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
2026-09-12 Document the CubXL boards on the Pi and how to address them (#212)
    An Arduino Uno R3 and a CH340 converter are now attached, both CubXL. Record
    their USB IDs, the Arduino's serial, and the stable by-id paths; insist on
    those over /dev/ttyACM0 and /dev/ttyUSB0, which change with enumeration
    order. Replace the stale "Pi is bare" paragraph with the current state.
2026-09-17 Corrected 2026-09-17 rePowder install transcript + bot-posted follow-up queue (#220)
    * Add corrected 2026-09-17 rePowder install transcript and a bot-posting queue
    Corrects the Tactiq voice-to-text of the install call with Bartosz (AMAZEMET)
    and Dave Laws for intent (13 mm not 30 mm coolant fittings, 16 A not 60 A,
    5N argon at 8 bar with a 0-10 bar regulator, sealing rod, AlSi10Mg, Valimet),
    with a summary and action items, and keeps the raw file alongside.
    Adds a workflow_dispatch workflow + script that posts a reviewed queue.json
    of issue comments / new issues as github-actions[bot], with a dry-run default
    and per-post markers so re-runs never double-post. The first queue carries the
    fol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
2026-09-21 Split the pipette work out of #171 into its own branch
    The pipette build is the Opentrons P20 GEN2 on the CubXL gantry, driven by a
    TMC2209 breakout off the capper's Arduino. Its setup and troubleshooting had
    grown to 78 of the 113 comments on #171 and roughly 250 files, interleaved with
    the Pi/CubOS provisioning that PR is actually about. This carries the pipette
    half on its own branch so the two threads stop tangling.
    Nothing here is new work. Every file is byte-identical to its copy on
    claude/issue-165-20260730-2304 at 0561306, except two additions:
    cubos/docs/pipette-setup-and-troubleshooting.md the status map: what is
    proven, what is eliminated, the four measurements left, an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
    [campaign.csv, experiments.csv, grbl_and_arduino_20260831.txt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]
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2026-09-22 Restate the terminal-block check by winding, not by wire colour
    The "look at the colours in the two terminal blocks" instruction assumed the
    harness carries science-jubilee's blue/red/black/green motor-lead colours
    through to the driver's screw terminals. Cubware's page, which this build
    follows, gives pin numbers only and names no colours at all, so the colours
    are a hint rather than a test.
    Restate the check in the form that always holds: both ends of one winding in
    1A+1B, both ends of the other in 2A+2B, traced by pipette header pin (3+4 one
    winding, 1+2 the other) rather than by colour. Note that block assignment and
    within-block order only reverse travel direction; only a winding split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
2026-09-23 Correct the OT-2 connection advice: no USB-B, and the app has split in two
    Timothy Commins checked the machine and reported no USB-B port, only ethernet
    and power. He is right, and the previous revision of opentrons-calibration.md
    was wrong to send him looking for one.
    - The rear panel is RJ45 + power. Opentrons' current docs list the side panel
    as "the on/off switch, an Ethernet port, and the power port"; the four USB-A
    ports are inside the enclosure and are for modules. First Run says to use an
    ethernet cable, with the supplied Ethernet-to-USB dongle on the *computer*
    end -- which is the source of the confusion, as is the internal USB-to-
    ethernet adapter that bridges the Comput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
2026-09-23 Record the cross-pair readings: 1A-2A is a dead short, and it explains DIAG
    Ben's wire-to-terminal map puts both ends of coil A in 1A+1B and both ends of
    coil B in 2A+2B, so the pairs are correctly grouped and the terminal-block swap
    hypothesis of 16.3 is retired without needing the meter.
    The new finding is 1A-2A = 0 ohm: the driver's two bridge outputs are shorted
    together. All four readings are self-consistent with that single topology, and
    a bridge-to-bridge short is one of the conditions that latches DIAG high - so
    the two previously separate symptoms collapse into one mechanism. It is also
    how the output stage gets destroyed, with the VREF pot at maximum, which makes
    the repair order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
2026-09-23 Record the direct-wire measurement: the windings are healthy, the ribbon is not
    Ben bypassed the 10-pin ribbon and FC-10P and wired the pipette straight to the
    driver's screw terminals. 1A-1B reads 4.3 ohms and 2A-2B reads 3.7 ohms -- real
    stepper windings, and the first ever measured here. Every previous reading of
    the same two pairs was kilohms to megohms. Nothing about the motor changed, so
    the open coil path was in the harness.
    New wiring-doc section 18 covers what that settles and what it does not: the
    cross pairs still need re-measuring to say whether the 1A-2A short left with the
    ribbon; the limit switch rode the same connector, so D9 is probably floating and
    the up-direction gate wi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
2026-09-23 Record the adapter's collapse, and prove the robot itself is healthy
    The OT-2 answers /health, /pipettes and POST /camera/picture with 0% packet
    loss at 0.647 ms, so the robot is not the fault. The RTL8153 on the Pi's
    SuperSpeed port is: across one session the survival time between a repair and
    the next 'Stop submitting intr, status -71' fell 2m42s -> 90s -> 18s, with the
    NO_LPM quirk set for the last two. Stage 1 of the recovery script no longer
    binds at all; only a stage 2 power cycle recovers it, and only with a 15 s off
    period rather than the default 6 s.
    deck-link-check-2026-09-23.jpg is the frame taken through the robot's own
    camera during one of those windows, rotated 180 per deck_ph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
2026-09-23 A blank /health page has three causes, so stop guessing between them
    The browser test told Timothy only that something was wrong, not which
    thing. Both ends of a link-local cable need a 169.254.x.x address and
    Windows only self-assigns one after DHCP times out; the robot's own
    address is self-assigned too and Opentrons warn it changes on reconnect;
    and the adapter may simply be dead. All three render identically as a
    page that does not load, and they need opposite fixes.
    find_ot2.ps1 separates them in one read-only pass: it lists adapters and
    addresses, sends the same _http._tcp.local PTR query the app's Devices
    tab sends and reports every responder, gathers candidate addresses from
    mDNS, t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
2026-09-23 Retarget the lab-computer instructions at Ubuntu, not Windows
    The lab computer runs Ubuntu, so the Windows-shaped advice in
    opentrons-calibration.md was unusable as written. The substantive difference is
    not cosmetic: Windows falls back to APIPA when DHCP times out, which is what
    made "wait 60 s for a 169.254 address" correct there. NetworkManager does not.
    ipv4.link-local defaults to "auto", meaning a link-local address is assigned
    only when ipv4.method is itself link-local, so a wired connection left on DHCP
    with nothing serving DHCP ends up with no IPv4 address at all, indefinitely.
    The fallback value that would behave like Windows landed in NetworkManager
    1.52; Ubuntu 24.04 ships 1.46. S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
2026-09-24 Record the cross-pair readings: the coil side is clean, DIAG is not
    1A-2A and 1B-2B now read megohms on the direct wiring. Together with the
    4.3/3.7 ohm windings of 18.1 that closes the coil-side diagnosis: the ribbon
    harness carried both the open coil path and the phase-to-phase short, and both
    left with it.
    That also raises the prior on a damaged output stage. The ribbon presented a
    bridge-to-bridge short while the pot sat at full clockwise and EN at 0 V, so
    the chip chopped into it across many sessions.
    New 19 covers:
    - the exoneration of the driver board as the source of the short
    - five things that can hold DIAG high other than a dead chip, chiefly that the
    datasheet's documented r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
2026-09-24 Flash the P20 GEN2 image; the trio was cut by a power loss
    The board had still been running the 2026-09-15 p20 build, re-confirmed by
    avrdude -U flash:v: against all three candidates. Its PRIME_POSITION is 36.0,
    a P300 plane, and aspirate() is computed inside the firmware — so with the
    coils now measuring 4.3 / 3.7 ohms it would have driven the plunger 8 mm past
    its mechanical bottom on every call. Flashed panda_vcl_p20gen2_20260917.hex
    first, verified at 17382 bytes, and re-checked both instrument paths after.
    That image carries tmc2209-softwareserial-read, and CMD 29 still returns
    comm = 0. That is the isolation rather than a disappointment: the software
    half of the readback is now fixe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
    [pipette_driver_measure.py]
2026-09-24 Record that the bench move could not have shown movement
    The first bench move showed no plunger motion. That is the predicted
    consequence of DIAG being asserted -- the TMC2209 disables its own output
    bridges on a driver error and holds them off until reset -- and the VREF
    pot had just been turned down by an unrecorded amount, so the test had two
    independent reasons to show nothing. It is also step 10 of the S19.3
    sequence, run while steps 1-8 were outstanding. So it is not evidence the
    board is broken, and the verdict still rests on the ENN reset and VREF at
    the wiper.
    One thing the data does now settle: DIAG reads 5 V at both ends of the
    pot's range, so the pot is not what holds it high an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
2026-09-25 Name the Ethernet cables to buy alongside the switch
    Cable Matters Cat 6, 10 ft, 24 AWG stranded bare copper: the 5-pack is
    $19.99, two dollars more than two singles. Checked 2026-09-25 from the
    livestream Pi, since Amazon blocks datacenter IPs. Also records the 14 ft
    option for a longer lab-computer run, and why to skip CCA and Cat 7/8.
2026-09-25 Give the OT-2 link the Pi's own Ethernet port
    The RTL8153 failed to probe on the 2026-09-25 cold boot (-71, "failed
    probe after 3 tries; giving up") and was unplugged, so the robot had no
    link. A link-local ot2-eth0 profile now outranks the stock DHCP
    netplan-eth0, so the robot's cable can go straight into the Pi's jack.
2026-09-25 Explain what restarts the OT-2 livestream Pi, and why its archive has gaps
    Read from the Pi, read-only, after it came back from a power cut today:
    - It reboots itself at 5 am, 1 pm and 9 pm (root crontab, from the AC's
    picam README), so YouTube stores each 8 h segment as its own video.
    - device.service restarts the stream program but gives up after 3 starts
    in an hour, and the local stream-watchdog skips a stopped service. A few
    minutes without network therefore leaves the stream down until the next
    scheduled reboot: five times in ten days, about 20 h of footage.
    - Power cuts on 09-23 and 09-25; the log stops mid-task with no shutdown
    steps. No under-voltage in any boot on record.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
2026-09-26 Move the tip rack to Ben's new A1 reading; take the recalibrated gantry file
    Ben recalibrated the gantry on its new bench (391 / 236.665 / 124) and sent
    new gantry and deck files, plus a jog reading with the pipette over tip A1:
    (265.0, 32.665). Converted with the NEW pipette offset (54.0, 12.999) to
    deck a1 (319.0, 45.664); pick_up_tip now commands gantry (265.000, 32.665,
    57.000), the reading exactly.
    The gantry file matches the controller: all 12 grbl_settings agree with a
    read-only $$ taken from the Pi (no motion). cnc.default_feed_rate_mm_min
    2000.0 is kept although the attachment lacks it; without it every move
    would run at CubOS's 3000 mm/min default.
    The trio still fails validation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
    [ben_6vials_tiprack.yaml, cub_xl_ben_pipette_capper.yaml, whatif_deck_seats2and3.yaml]
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2026-09-30 Move vials +33 mm, fix tipped travel_z to 86, flash STEPS_PER_MM 796; run stopped on a USB over-current trip
    Ben moved vial_1 and vial_2 +33 mm in Y so the pipette can reach vial_1, and
    asked for the 87 -> 86 travel_z fix and a run. Gates on the runner and the Pi:
    validate PASS, mock 12/12, passive_shadow 0 / 0.
    Before the run the Arduino got the P20 GEN2 image with STEPS_PER_MM 796 for
    the Tic's 1/8 step (5 bytes different from the 09-17 image, verified before
    and after): with 1592 the connect-time prime would have driven the plunger
    ~56 mm, past the end of its travel. HOME stops on the switch in 0.94 s.
    The run homed, parked and started decap vial_1. At 00:23:24 UTC all four of
    the Pi's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
    [ben_6vials_tiprack.yaml]
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2026-09-30 Trio 12/12 on the Tic T500: every plunger command executed, no steps lost
    The GRBL controller was found factory-reset (G54 zeroed, travel
    400/300/100, soft limits off). Restored only what the gantry file checks
    plus the G54 offset, from the 2026-09-26 record, with no motion. The
    pre-run HOME (12.687 s) and post-run HOME (12.680 s) started from the
    same position, so no steps were lost across the run.
    [campaign.csv, experiments.csv, manifest.csv]
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2026-10-01 Trio 12/12 in 124 s with all three speed changes (was 238 s); no plunger steps lost
    Campaign 75, run through the new cubos/tools/cubxl_run.py: 47 G01 in 55.2 s
    (was 127.5), two homes 28.6 s (was 38.2), plunger 20.3 s (was 45.7). The
    ejector push stayed at 4.65 s; a post-run plunger HOME implies 27.99 mm against
    the firmware's 28.0. Tic: no errors, VIN 9.0-11.3 V; no USB events.
    Also: the runner refuses protocols with a breakpoint (headless), labels its
    wall time correctly; docs record the udev rule that lets ticcmd run without
    sudo, the ~/byu-vcl-pipette worktree, the new firmware image, and the
    measured speed table.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
    [campaign.csv, experiments.csv, manifest.csv]
2026-10-01 cubxl_run.py: write results to ~/cubxl_runs/<name>, outside the checkout
    So git pull on the Pi's worktree never collides with a run's untracked folder.
    [cubxl_run.py]
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2026-10-02 Replace Ben's 2026-10-02 gantry and deck files with his 19:54Z corrections
    Ben's 19:35Z deck file "didn't save the changes". The corrected one moves
    both vials from deck x 115 to 136.668 (y 45.08/78.08 -> 45/78) and the tip
    rack from (294, 92, 62) to (291.332, 89, 59). The gantry file changes only
    factory_z_travel_mm 125 -> 124; it now carries working_volume max
    361/278/122 itself, so it is verbatim. Both bodies parse identically to the
    attachments.
    [ben_2vials_tiprack.yaml, cub_xl_ben_3_instrument.yaml]
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2026-10-02 Record pipette_test_20261002: unplugged by Ben, then E-stopped by Ben
    Attempt 1 stopped at 0/12 when Ben unplugged the gantry (the deck file
    he had sent had not saved his edits). Attempt 2 ran with that stale deck
    file because this session never re-read the issue; Ben E-stopped it
    during step 2 (decap vial_1, Z descending to 99), and the session killed
    its processes after finding the HOLD file. Nothing beyond step 1
    completed; no tip, no cap held; Tic de-energized by hand.
    The stale configs move from cubos/configs/ into the run records so they
    can't be run by mistake; Ben's corrected files are another session's.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
    [campaign.csv, experiments.csv, manifest.csv]
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2026-10-02 pipette_test_20261002c: 12/12 on Ben's 2026-10-02 gantry and deck files
    Campaign 98, 20:04:59Z -> 20:07:39Z, 160 s wall. All checks and gates
    passed first (validate, mock 12/12, both shadows), and the G-code sent
    matches the traced targets. Plunger HOME check +0.04 mm, 0 kernel USB
    lines. Frames after steps 2, 3, 4, 8, 9 and 10.
    Two things recorded for Ben: the Tic's VIN now sags with gantry motion
    (min 7.4 V in the final home; the same step-1 moves held 10.7-11.0 V at
    19:58), and the previous session's 19:58Z run, made with the superseded
    deck file before HOLD existed, ended when GRBL went silent mid-move with
    no USB event. That session's note and the gantry log excerpt are in
    previous_ses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
    [campaign.csv, experiments.csv, manifest.csv]
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2026-10-06 pipette_test_20261006: 12/12 on the Tic T500 after the 10-05 rewire
    Re-runs pipette_test on the CubXL with the 2026-10-02 gantry and deck files
    (byte-identical to pipette_test_20261002c), now with frames from both cameras.
    Before any motion: the 10-05 limit-switch probe, run on the Tic, shows the
    plunger moves and DIR LOW is up, with no lost steps up to 10,000 steps/s. A
    checks-only pass found GRBL, the Arduino, the Tic settings and all four gates
    in order. Protocol 12/12 in 141 s. The G-code matches 10-02c apart from one
    built-in decap retry on vial_1. Post-run HOME check -0.00 mm. Tic VIN
    8.1-11.4 V, no errors. The *.log files are force-added (gitignored).
    Refs #169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
    [campaign.csv, experiments.csv, manifest.csv]
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2026-10-07 tmc2209_spreadcycle_20261007: fix B flashed, probe passes with everything plugged in, pipette_test 12/12
    The probe as is (EN back on A4, UART on pin 9) failed twice: 18:40Z (the
    cancelled run) and 18:49Z. Fix B (disableStealthChop) flashed at 18:52Z and
    verified; the probe then passed and pipette_test ran 12/12 with --no-tic.
    Raw logs, the new hex and its patch; write-up follows.
    [campaign.csv, experiments.csv, manifest.csv]
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2026-10-09 pipette_test_mix_20261009b: 12/12 with mix in place of aspirate and blowout
    Second attempt, after Ben fixed the capper wiring that stopped the first at
    decap vial_1. The probe was re-run first. Each mix sent 6 ASPIRATE and 6
    DISPENSE and cycled the gantry between Z 56 and 57. The post-run plunger HOME
    check was -0.03 mm. Adds the logs, the probe and frames from both cameras, and
    records the cause and a CubOS failure-retract bug in the first attempt's README.
    [campaign.csv, experiments.csv, manifest.csv]
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2026-10-10 Pico W: per-reading LED current and integration time, installed over USB; AS7341 Fig. 19 response curves
    Firmware (installed 2026-10-10 10:42 MDT, after a full backup of all 33 files,
    tested from RAM first, then from flash after a hard reset):
    - settings now accepts gain, atime (0-255), astep (0-65534) and led_ma (0 or
    even 4-20 mA, the board driver's own limits); integration capped at 1500 ms
    per half. Anything left out reads exactly as before (128x, 100/999, LED off),
    and every setting is put back after each reading, including on a failed read.
    - replies add atime/astep/integration_ms/full_scale/led_ma to sensor_settings,
    and both halves' Clear and NIR as sensor_extra.
    - test_setti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
    [as7341-response-fig19.csv]
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
